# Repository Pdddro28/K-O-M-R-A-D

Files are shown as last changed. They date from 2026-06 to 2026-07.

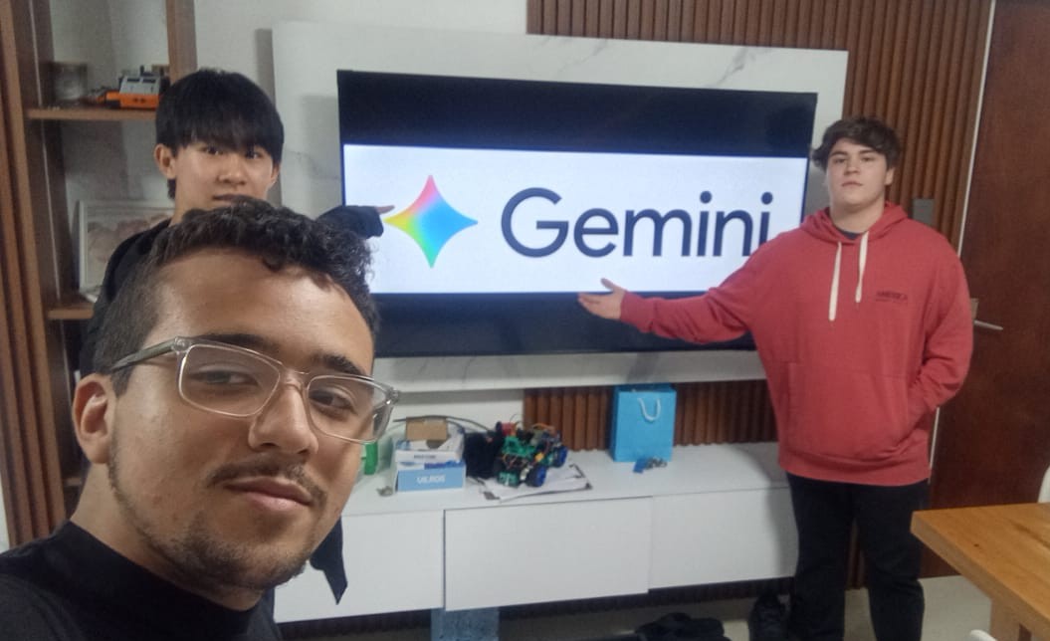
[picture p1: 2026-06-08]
t-photos/Funny_pic.jpg

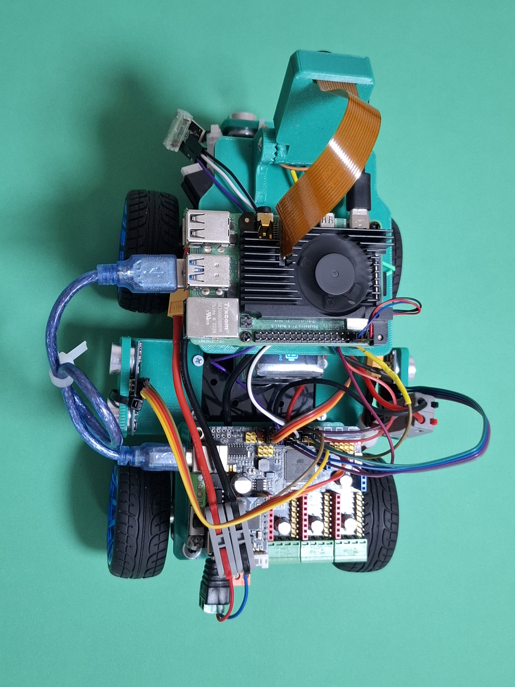
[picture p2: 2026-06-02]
v-photos/Upper-Pov.jpg

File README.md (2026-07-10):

**If you want to see this repository in English, [click here](https://github.com/Pdddro28/K-O-M-R-A-D/blob/main/README_EN.md)**

``` Para mejor visualización, se recomienda ver el repositorio en la computadora ```

# WRO 2026 Future Engineers – LNM

<div align="center">
	
<img width="840" height="407" alt="WhatsApp Image 2026-06-19 at 11 51 57 PM" src="https://github.com/user-attachments/assets/cee364df-eeba-4338-8f2a-14949adb755b" />

</div>

Bienvenidos al repositorio de GitHub del **Equipo LNM**, anteriormente conocido como Ars Machina, que compite en la categoría **World Robot Olympiad™ (WRO®) Future Engineers 2026**. Nuestro equipo está formado por David Wang y Pedro Catamo que han diseñado un vehículo autónomo compacto e innovador para hacer frente a los retos dinámicos de la competición WRO 2026.

## **Índice**

**1. [Estructura de carpetas](#estructura-de-carpetas)**

**2. [El equipo](#el-equipo)**

**3. [Nuestro robot](#nuestro-robot)**

**4. [Sistemas electrónicos](#sistemas-electronicos)**

**5. [Sistemas mecánicos](#sistemas-mecanicos)**

**5. [Arquitectura de software](#arquitectura-de-software)**

---

## **Estructura de carpetas** 

Esta es la estructura de carpetas de nuestro repositorio:

| Carpeta | Contenido técnico | Documentación detallada |
|---|---|---|
| **models** | **Diseños 3D**<br>• Piezas del carro| [Explora los modelos 3D](models/README.md) |
| **schemes** | **Sistemas eléctricos**<br>• Diagramas de cableado<br>• Gestión de la alimentación<br>• Esquemas de componentes| [Explora la documentación de esquemas y cableado](schemes/README.md) |
| **src** | **Algoritmos de software**<br>• Lógica de navegación<br>• Fusión de sensores<br>• Sistemas de control | [Explora la documentación de software y algoritmos](src/README.md) |
| **t-photos** | **Documentación del equipo**<br>• Perfiles de los miembros | [Explora la documentación de fotos del equipo](t-photos/README.md) |
| **v-photos** | **Documentación del vehículo**<br>• Vistas desde múltiples ángulos | [Explora la documentación de fotos del vehículo](v-photos/README.md) |
| **video** | **Validación del rendimiento**<br>• Demostraciones del desafío<br>• Pruebas de ingeniería | [Explora la documentación de los vídeos de rendimiento](video/README.md) |

---

## **El Equipo** 

<div align="center">
	
<img width="1280" height="720" alt="Team_pic (1)" src="https://github.com/user-attachments/assets/156c3c29-799e-44e6-a7f0-629da61873b8" />

</div>

### **Miembros:**

- **David Wang**
   
	Nacido en: 01/04/2011 (15 años)

	Estudio: 3º año en la U.E.C. Eduardo Blanco

  	Gmail: davidwangwu104@gmail.com
  	  
- **Pedro Catamo**
   
 	Nacido en: 28/01/2009 (17 años)
   
  	Estudio: 5º año en la U.E.C. Eduardo Blanco
   
 	 Gmail: pedrocatamo.2009@gmail.com

- ### **Coach:**

- **Jesús Alcalá**
   
  Nacido en: 18/11/2005 (21 Años)
   
  Estudio: Ingenieria en computación & Ingenieria informática
   
  Gmail: Jdam50002@gmail.com

---

### Diseños anteriores:
  
<div align="center">
	
| Foto | Nombre | Descripción |
|---|---|---|
| <img width="920" height="920" alt="Captura de pantalla 2026-06-17 185504" src="https://github.com/user-attachments/assets/36166165-a542-42d6-a771-41a60693a399" /> | **Cyber Cooper** | En 2023 teníamos pensado diseñar el coche desde cero, modelando e imprimiendo nuestras propias piezas en 3D, incluidos el chasis y el sistema de dirección. Aunque al principio parecía una buena idea, a medida que avanzábamos empezamos a encontrarnos con un problema tras otro, y nos dimos cuenta de que nuestro diseño actual nos acarrearía más dificultades. Al final, hicimos todo lo que pudimos dentro de las limitaciones de tiempo que teníamos. |
| <img width="920" height="920" alt="front2" src="https://github.com/user-attachments/assets/ce130237-cc0b-4aa9-a620-0aea287408c2" /> | **Cooper** | En 2024 desarrollamos un chasis con piezas 3D estructurado en dos niveles. El nivel inferior albergaba los sensores y la electrónica de bajo nivel, mientras que el superior sostenía las baterías y la Raspberry Pi 3 para optimizar el espacio. Aunque logramos un gran avance estético y funcional, sufrimos lecciones duras en pista: el peso excesivo provocó la flexión de los acoples en la transmisión trasera, lo cual, a su vez, generó problemas severos de fricción mecánica entre las piezas impresas en 3D. |
| <img width="920" height="920" alt="front" src="https://github.com/user-attachments/assets/804b3d7f-3500-4351-a917-ccf781029804" /> | **Halbi** | En 2025 teniendo en cuenta los recursos de los que disponíamos en ese momento, nuestra idea principal era rediseñar el Cybercooper, modificando la base y la estrategia existentes y utilizando mejores componentes electrónicos; empezamos a imprimir las nuevas piezas con material blanco y a pensar en mejores formas de montar el sistema de dirección del coche. Al final, decidimos utilizar una base prefabricada para el chasis; la razón principal fue ahorrar tiempo (y dolores de cabeza) con el diseño mecánico, lo que nos permitía dedicar más tiempo a la electrónica y la programación. |
| <img width="920" height="920" alt="WhatsApp Image 2026-06-18 at 7 39 40 PM" src="https://github.com/user-attachments/assets/ca9f62ff-7b8b-452a-97de-95ebf12dc0ef" /> | **The Fridge** | En 2025 a diferencia de los modelos anteriores que pertenecían a nuestro coach, "The Fridge" fue un diseño construido enteramente por nosotros. Aquí dimos el salto a la geometría Ackermann e imprimimos la gran mayoría de las piezas en 3D. A nivel motriz, usamos un motor DC con un engranaje acoplado para traccionar ambas ruedas. Físicamente le instalamos 3 sensores ultrasónicos, una Raspberry Pi 4 y un giroscopio MPU6050, pero por falta de tiempo y severos problemas de configuración, la Raspberry y el IMU quedaron como peso muerto y terminamos controlando todo únicamente desde la MegaPi. Sufrimos muchísimo: las piezas de la dirección impresas en 3D se rompían constantemente por el estrés, y programar la navegación autónoma en Arduino dependiendo de puros rebotes ultrasónicos fue casi imposible. |

</div>

---

# 1- Mobilidad y diseño

 - ### Halbi The Green: 

    - ### Fotos del vehiculo:

	<div align="center">

	| | **Diferentes ángulos del carro** | |
	|---|---|---|
	| **Superior** | **Derecha** | **Izquierda** |
	| <img width="560" height="580" alt="Upper-Pov" src="https://github.com/user-attachments/assets/74863cc8-5128-49cf-845e-0f087c50bcf1" /> | <img width="560" height="580" alt="RightSide-Pov" src="https://github.com/user-attachments/assets/8b9c2020-cc18-441f-9152-c86d9a233b10" /> | <img width="560" height="580" alt="LeftSide-Pov" src="https://github.com/user-attachments/assets/cdbabe27-6e45-4dab-98e6-e63b24ed7371" /> |
	|**Frontal** | **Trasero** | **Inferior** |
	| <img width="560" height="580" alt="Front-Pov" src="https://github.com/user-attachments/assets/d9b65dd5-ca97-4087-ba20-77f7cbeb4bf6" /> | <img width="560" height="580" alt="Back-Pov" src="https://github.com/user-attachments/assets/dd1737be-1173-4cae-9229-25821f05dc22" /> | <img width="560" height="580" alt="Lower_Pov" src="https://github.com/user-attachments/assets/4c77c94d-d121-4708-b3ed-74bc2d390fe6" /> |
	
    </div>

	- ### Especificaciones mecánicas principales: 

		- **Dimensiones totales: 24.4 cm (largo) × 15.4 cm (ancho) × 15.9 cm (alto).**
		- **Peso del carro: aproximadamente 1.2kg.**
		- **Sistema de tracción: Tracción Trasera Mecánica Bifásica.**
		- **Sistema de dirección: Geometría Ackermann.**
	
	- ### Mecanismo de Dirección Ackermann

		El vehículo utiliza una geometría precisa basada en el **Principio de Dirección Ackermann** para conquistar curvas cerradas con cero deslizamiento lateral y un desgaste mínimo de los neumáticos.

		* **La Física Detrás del Principio:** Cuando un vehículo entra en una curva, la rueda delantera interior sigue un radio concéntrico más cerrado y pequeño que la rueda exterior. Si ambas ruedas giraran exactamente al mismo ángulo, los neumáticos lucharían entre sí, provocando que el neumático exterior se arrastre, pierda agarre mecánico e introduzca vibraciones estructurales severas que arruinarían el seguimiento visual de los carriles. Para resolver esto, la geometría mecánica obliga a la rueda interior a pivotar a un ángulo más profundo que la rueda exterior, asegurando que las cuatro ruedas roten alrededor de un único centro instantáneo de curvatura (ICC) común.

		* **La Ejecución Mecánica:** Un servo digital **MG996R** de alto par ($11 \text{ kg}\cdot\text{cm}$ de par) se ancla al mamparo delantero mediante un soporte de aluminio en forma de L mecanizado a medida para eliminar la deflexión estructural. El brazo del servo acciona una cremallera de dirección de doble enlace conectada a tirantes asimétricos y manguetas de dirección. Los brazos de dirección están angulados hacia el interior, apuntando al centro del eje trasero, completando el clásico "Trapezoide de Ackermann". Este diseño mecánico exacto convierte el desplazamiento lineal del servo en ángulos de rueda no lineales de forma automática.

		* **El Control Digital y Calibración:** El MG996R es controlado por un tren de pulsos PWM por hardware continuo y libre de fluctuaciones (*jitter*) a $50\text{Hz}$ directamente desde el microcontrolador MegaPi. La dirección está rígidamente mapeada y calibrada a una banda muerta de software donde los $80^\circ$ representan el centro geométrico absoluto. Los puntos finales mecánicos están limitados por software entre $40^\circ$ (Máximo Izquierda) y $105^\circ$ (Máximo Derecha) para evitar que los eslabones de la dirección alcancen un bloqueo mecánico o fuercen los límites de pérdida del motor.

	- ### ¿Qué es la Geometría Ackermann? 

		Entendiendo la Matemática y Cinemática Ackermann, en robótica móvil tradicional (como los robots de la categoría *RoboMission*), se utiliza la tracción diferencial porque es matemáticamente simple: varías la velocidad de dos motores y el robot gira sobre su propio eje. Sin embargo, a altas velocidades, la tracción diferencial es inestable e impredecible.

		**La Geometría Ackermann** resuelve esto mediante un principio puramente mecánico. Para que un vehículo gire sin deslizarse lateralmente, las líneas extendidas desde los ejes de todas las ruedas deben cruzarse en un único punto en el espacio: el **Centro Instantáneo de Rotación (CIR)** o ICC.

		La ecuación matemática fundamental que gobierna esta cinemática es:
		<div align="center">
	
		$$\cot(\theta_{\text{out}}) - \cot(\theta_{\text{in}}) = \frac{w}{L}$$
		
		</div>
		
		Donde:
		
		* $\theta_{\text{in}}$ es el ángulo de giro de la rueda interna.*
		* $\theta_{\text{out}}$ es el ángulo de giro de la rueda externa.*
		* $w$ es el ancho de la vía (*track width* o distancia entre las ruedas frontales).*
		* $L$ es la batalla del carro (*wheelbase* o distancia entre el eje delantero y trasero).*

		Dado que la cotangente crece más rápido a ángulos pequeños, esta relación obliga mecánicamente a que $\theta_{\text{in}} > \theta_{\text{out}}$ de forma automática en cualquier curva, abriendo el ángulo de la rueda exterior para que dibuje un círculo más grande.

		<div align="center">
  
		<img width="567" height="600" alt="17523247_203569336801744_2788986523412924047_n" src="https://github.com/user-attachments/assets/c36a271c-b45c-492a-805e-b107851429cd" />
		
		</div>

	- ### Propulsión Electrónica 2WD con Transmisión Mecánica Bifásica 

		La fuerza motriz de la plataforma se genera mediante un sistema de tracción trasera (2WD) de alto rendimiento, el cual rompe con los esquemas tradicionales de acoplamiento directo al integrar una transmisión mecánica desmultiplicada de dos velocidades por engranajes cilíndricos rectos.

		* **Arquitectura del Sistema de Transmisión:** A diferencia de las configuraciones comunes que acoplan la rueda directamente a la caja reductora del motor, este diseño monta el motor RS380 en una disposición paralela superior sobre un bloque de soporte rígido. La potencia se transfiere desde el eje primario del motor hacia un eje secundario de tracción inferior mediante un tren de engranajes expuesto con dentado recto. Este sistema de dos velocidades mecánicas intercambiables permite configurar el robot según las exigencias de la pista:
  		1. **Relación de Fuerza/Torque (Primera Velocidad):** Optimiza el desmultiplique para obtener la máxima aceleración y un control milimétrico en curvas cerradas u obstáculos, ideal para tramos revirados. 
  		2. **Relación de Velocidad Final (Segunda Velocidad):** Reduce la pérdida de revoluciones para aprovechar la inercia lineal en rectas largas, garantizando una alta velocidad de crucero sin saturar el consumo eléctrico.

		<div align="center">
  
		<img width="515" height="218" alt="Sistema de transmision de 2 velocidades K-O-M-R-A-D" src="https://github.com/user-attachments/assets/da8175e6-313d-42d6-bd3b-b1318082536f" />
		
		</div>

		* **Especificaciones Técnicas de los Motores (RS380):** El bloque motriz confía en motores de CC con escobillas imantadas, seleccionados específicamente por su curva de respuesta dinámica y tolerancia a picos transitorios de carga.

	    * **Voltaje Nominal:** $12\text{V}$ (Operando a un voltaje nominal de celda de $11.1\text{V}$ mediante una batería LiPo 3S para asegurar la estabilidad térmica).
   
 		* **Corriente de Vacío (No-load):** $0.3\text{A}$ | **Corriente de Arranque/Pérdida (Stall):** $3\text{A}$ de protección en el driver.
   
 		* **Velocidad de Rotación de Fábrica:** $15000\text{ RPM}$ en el núcleo del motor, reducida internamente y ajustada finalmente por el engranaje externo para entregar una velocidad final estimada de transferencia de aprox. $450\text{ RPM}$ en el eje de la rueda.

		* **Análisis Cinemático y Cálculo de la Velocidad Teórica Absoluta:**
		Para determinar el rendimiento del chasis en pista y calibrar las ventanas de tiempo por vuelta (como el parámetro de control `lap_time = 4.3`), se realiza el cálculo cinemático basado en el diámetro de las ruedas motrices de $6.5\text{ cm}$ ($0.065\text{ m}$). Evaluamos la circunferencia de rodadura ($C$) y la velocidad lineal máxima teórica ($V$):

	<div align="center">
	
	$$C = \pi \times 0.065\text{ m} \approx 0.2041\text{ m}$$

	</div>

	Transformando las revoluciones por minuto del eje secundario de la transmisión a revoluciones por segundo y multiplicando por el desarrollo de la circunferencia, obtenemos la velocidad de avance del chasis:

	<div align="center">
	
	$$V = \frac{450\text{ RPM}}{60} \times 0.2041\text{ m} \approx 1.53\text{ m/s}$$
		
	</div>

	Este valor de $1.53\text{ m/s}$ representa la velocidad límite ideal de la plataforma. En condiciones reales de competencia, este vector se modula por software mediante los comandos de velocidad (`speed = 90` u `80`) para absorber la fricción estática del suelo, la resistencia al avance de los rodamientos y las demandas instantáneas de corriente solicitadas por la MegaPi al gestionar el cambio de inercias.

	- ### 3D Printed Parts:

   		- #### **Piezas:**

		<div align="center">
			
		| Component & Preview | Design & Geometry | Engineering Purpose |
		|---|---|---|
		| **Battery Case** <br><br><img width="400" height="400" alt="BatteryCase" src="https://github.com/user-attachments/assets/a5362844-dd0e-4073-bef8-bb034bae3ad9" /> | Diseñado como una jaula de torre vertical estructurada con cuatro pilares reforzados en cada lado, integrada directamente sobre una base de montaje sólida con ojales para tornillos en las esquinas. Las paredes laterales cuentan con grandes recortes circulares para minimizar el peso del material mientras permiten un flujo de aire pasivo máximo para evitar el estrés térmico en las celdas LiPo durante altas tasas de descarga. El pilar superior incluye ojales de retención ranurados para una sujeción segura de las correas. | Centraliza la masa combinada de las celdas de la batería verticalmente a lo largo del eje geométrico central del chasis. Este diseño de jaula abierta garantiza un acceso rápido para el reemplazo de la batería entre carreras, al tiempo que proporciona una contención estructural rígida contra las fuerzas de inercia laterales durante giros a alta velocidad. |
		| **Camera Case** <br><br><img width="400" height="400" alt="CameraCase" src="https://github.com/user-attachments/assets/7adbc42b-15eb-4677-a0a4-8d9b3c98bab3" /> | Una carcasa protectora rectangular y compacta, diseñada específicamente para encapsular el sensor IMX219 (Arducam). La sección inferior integra una robusta bisagra de pivote cilíndrico que cuenta con dientes de bloqueo externos (perfil de engranaje recto) diseñada para engranar perfectamente con una base de montaje correspondiente para el bloqueo mecánico del ángulo. | Protege el delicado PCB de la cámara de los escombros externos o de los impactos directos en la pista. La bisagra engranada entrelazada permite ajustar y bloquear mecánicamente el ángulo de inclinación de la cámara a un ángulo preciso de 15 grados hacia abajo, evitando cualquier cambio no deseado en el lente causado por las vibraciones de alta frecuencia del chasis durante la operación. |
		| **MegaPi Case** <br><br><img width="400" height="400" alt="MegaPiBase (1)" src="https://github.com/user-attachments/assets/8db95bf2-a29a-468c-ace8-e21bb1fae9f6" /> | Una bandeja robusta de perfil bajo equipada con cuatro soportes verticales integrados de alta resistencia posicionados en las esquinas para asegurar el PCB principal. La placa base cuenta con guías de distribución internas y cortes de holgura estructural para evitar los componentes en la parte inferior de la placa, manteniendo el perfil lo más cercano posible al chasis. | Funciona como una cuna mecánica rígida para la electrónica de potencia de bajo nivel. Al elevar el PCB mediante los soportes integrados de 3 mm, evita cortocircuitos eléctricos con el chasis al tiempo que amortigua las vibraciones. El perímetro completamente abierto garantiza el acceso inmediato a los terminales de tornillo del motor, los rieles de alimentación y los puertos de sensores para el mantenimiento en campo. |
		| **RaspberryPi Base** <br><br><img width="400" height="400" alt="RaspberryPiBase (1)" src="https://github.com/user-attachments/assets/2403b708-2e1d-4360-9504-aae68c0027d1" /> | Una plataforma modular plana de nivel medio que cuenta con cuatro soportes de esquina integrados para montar la Raspberry Pi 4 de forma segura. La sección frontal de la base integra un montaje de bisagra de doble oreja equipado con dientes de bloqueo internos que se acoplan directamente con la bisagra de la carcasa de la cámara (Camera Case). | Sirve como un puente estructural de doble propósito. Proporciona un montaje estable y elevado para la computadora de a bordo de alto nivel, asegurando una disipación óptima del calor a través de la convección natural para evitar el estrangulamiento térmico del CPU. Al mismo tiempo, su montaje engranado integrado bloquea firmemente el ensamblaje de la cámara en la parte delantera, eliminando la necesidad de componentes adicionales y ahorrando valioso espacio en el chasis.|
		| **Ultrasonic Case** <br><br><img width="400" height="400" alt="UltrasonicSensorCase" src="https://github.com/user-attachments/assets/f9696c40-13e6-46b5-9712-2d7849a80005" /> | Un soporte protector compacto de doble barril hecho a medida para encapsular firmemente los cilindros del transmisor y receptor del módulo del sensor ultrasónico. Cuenta con pestañas de montaje traseras integradas y bridas inferiores para un acoplamiento mecánico continuo a las vigas transversales delanteras de la estructura del chasis. | Proporciona una carcasa rígida y aislada de vibraciones que mantiene el sensor ultrasónico perfectamente perpendicular al plano horizontal de la pista. Esta alineación precisa elimina la distorsión de la señal acústica y la dispersión de las ondas, garantizando mediciones de distancia en tiempo real altamente precisas para la detección de obstáculos y mapas de frenado de emergencia. |

		</div>

		- #### **Impresora:** Se usó las impresoras Creality Hi y Creality K1.

   			- **Creality Hi:** Es una de las propuestas más recientes de Creality, diseñada con un fuerte enfoque en competir directamente en el mercado de impresión multicolor accesible.
        
        		- **Volumen de construcción (lo que puedes imprimir):** $260 \times 260 \times 300\text{ mm}$. Es un tamaño intermedio-alto, excelente para robótica porque te permite hacer chasis completos en una sola pieza sin tener que segmentarlos.
            
          		- **Dimensiones de la máquina:** $409 \times 392 \times 477\text{ mm}$ (Peso: $8.75\text{ kg}$).
  
        		Es una impresora cartesiana de alta velocidad equipada con motores step-servo en los ejes X/Y para evitar la pérdida de pasos. Su gran fuerte es la compatibilidad nativa con el sistema CFS (Creality Filament System), un módulo externo tipo "banco de filamentos" que te permite alternar de forma automatizada hasta 4 colores diferentes (o hasta 16 si encadenas 4 módulos). Su velocidad máxima es de $500\text{ m/s}$ con una aceleración de $12,000\text{ mm/s}^2$ y alcanza los $300^\circ\text{C}$ en la boquilla.
  
        		- **¿Qué tan buena es?**
  
           			* **Puntos Fuertes:** Estructura de aluminio fundido extremadamente rígida, calibración y nivelación 100% automática por sensor de deformación, y detección inteligente de enredos o fin de filamento. Si compras la versión Combo (con el CFS), es una máquina brutal para piezas que necesitan soportes solubles o combinar materiales rígidos y flexibles.
  
       				* **Puntos Débiles:** Al no ser cerrada de fábrica (diseño abierto), imprimir materiales técnicos propensos a contraerse como el ABS o ASA de forma consistente puede ser complicado sin construirle una cabina externa.
          
	   			- **¿Se recomienda usarla a futuro?**
  
   					Sí, totalmente. Al ser una plataforma moderna, cuenta con el soporte de software más actualizado (Creality Print 5.1 / OrcaSlicer) y está diseñada bajo el ecosistema de cambio de filamento automático, que es hacia donde se mueve toda la industria. Es una excelente inversión a largo plazo para un taller.

			- **Creality K1:** Lanzada originalmente como la respuesta directa de Creality a la serie P1 de Bambu Lab, es una máquina de nivel profesional diseñada para velocidad pura y materiales exigentes.

     			- **Volumen de construcción (lo que puedes imprimir):** $220 \times 220 \times 250\text{ mm}$. Es un espacio estándar (ligeramente más pequeña que la Creality Hi).
        
    			- **Dimensiones de la máquina:** $355 \times 355 \times 480\text{ mm}$ (Peso: $12.5\text{ kg}$).
  
        		Utiliza un sistema cinemático CoreXY donde el cabezal se mueve de forma ultraligera en los ejes X/Y usando correas cruzadas, mientras la cama solo baja en el eje Z. Al estar completamente cerrada con paneles de vidrio y acrílico, retiene el calor interno en la cámara de impresión. Alcanza una velocidad de $600\text{ mm/s}$ y una aceleración masiva de $20,000\text{ mm/s}^2$ gracias a su firmware basado en Klipper (Creality OS).
  
   				- **¿Qué tan buena es?**
  
   					* **Puntos Fuertes:** Es una bestia para materiales técnicos. Su cámara cerrada es perfecta para imprimir PETG, ABS, ASA y Nylon sin sufrir warping (despegue de bordes). Su aceleración es casi el doble que la de la Creality Hi, reduciendo los tiempos de impresión de piezas mecánicas complejas drásticamente.
  
       				* **Puntos Débiles:** Las primeras unidades que salieron al mercado (lotes de 2023) sufrieron de problemas en el extrusor (versión V1) y en el hotend. Creality corrigió esto en las versiones posteriores (extrusor con palanca brillante y boquilla tipo Unicorn), por lo que si adquieres una hoy, te aseguras de tener la versión corregida y madura.
          
	   			- **¿Se recomienda usarla a futuro?**
  
   					Sí, pero bajo ciertas condiciones. Sigue siendo una máquina excepcionalmente rápida y robusta para piezas de ingeniería. Sin embargo, debes tener en cuenta que la K1 original no es compatible con sistemas de impresión multicolor multihilo modernos de manera nativa (esa característica se reservó para la serie K2 con el nuevo CFS).

		- #### **PETG vs PLA:**

		<div align="center">

		|  | PETG | PLA |
		|---|---|---|
		| **Durabilidad y Resistencia** | Alta durabilidad y tenacidad superior: Al estar modificado con glicol, el PETG impide la cristalización del polímero, resultando en un material altamente tenaz. Bajo esfuerzos mecánicos por impacto, sus cadenas moleculares tienen la flexibilidad necesaria para deformarse elásticamente y absorber la energía cinética del choque. Esto evita la propagación de grietas, haciéndolo ideal para piezas expuestas a colisiones continuas. | Baja durabilidad ante cargas dinámicas: El PLA posee una estructura molecular rígida y cristalina que le otorga una alta dureza superficial, pero carece de la capacidad de disipar energía de forma elástica. Ante colisiones directas o impactos bruscos contra los bordes de la pista, el material estresa sus uniones de capa interlace y tiende a la fractura frágil, quebrándose de manera repentina y catastrófica en lugar de flexionarse. |
		| **Resistencia y Estabilidad Térmica** | Excelente inmunidad térmica: Mantiene su integridad estructural y rigidez mecánica en entornos de trabajo de hasta 75°C a 80°C sin experimentar ablandamiento ni distorsión geométrica. Esta propiedad permite montarlo con total seguridad como soporte directo del tren motriz o de placas electrónicas, resistiendo el calor generado por la fricción mecánica y los picos de corriente sin ceder. | Vulnerable al estrés térmico: Su temperatura de transición vítrea (punto de ablandamiento) es críticamente baja, situándose entre los 50°C y 55°C. Si se utiliza en componentes en contacto directo con motores DC bajo carga pesada o reguladores de voltaje que disipan calor por conducción, el PLA pierde su rigidez rápidamente, sufriendo deformaciones geométricas permanentes que descalibran el chasis. |
		| **Rigidez Estructural y Flexión** | Módulo elástico moderado (Flexibilidad elástica): Posee una naturaleza semirrígida que le permite soportar vibraciones mecánicas, torsiones y cargas dinámicas continuas sin sufrir fatiga de material. Si bien cede ligeramente ante fuerzas extremas antes de romperse, esta flexibilidad estructural absorbe las oscilaciones del terreno, protegiendo los componentes internos. | Módulo elástico muy elevado (Rigidez absoluta): Presenta una resistencia a la flexión superior, lo que significa que no se dobla ni se deforma bajo cargas estáticas moderadas. Esta ausencia de flexibilidad elástica es una ventaja técnica para piezas estáticas del robot que requieren mantener una posición fija e invariable, neutralizando cualquier flexión parasitaria o pandeo. |
		| **Resistencia Química y Ambiental** |  Alta inercia química e hidrofobicidad: Es químicamente inerte y exhibe una resistencia sobresaliente ante aceites, grasas, lubricantes mecánicos y alcoholes de limpieza. Al ser completamente hidrofóbico, no se debilita por la humedad ambiental tras su impresión y su alta estabilidad frente a la radiación UV garantiza que las piezas mantengan sus propiedades mecánicas intactas. | Sensible a la degradación a largo plazo: Al ser un biopolímero derivado de fuentes orgánicas, es propenso a la degradación acelerada bajo la exposición continua a rayos UV o cambios de humedad drásticos. Además, su resistencia química frente a agentes externos como alcoholes, aceites o lubricantes de hardware es limitada, lo que puede debilitar las paredes de la pieza con el tiempo. |
		| **Precisión Dimensional y Encajes** | Tolerancias moderadas y propenso a hilos: Al requerir temperaturas de extrusión más altas, el material experimenta una mayor contracción térmica al enfriarse, lo que exige calibrar el flujo para evitar variaciones dimensionales en encajes milimétricos. Además, su alta viscosidad tiende a generar stringing (hilos finos) que requieren postprocesado en zonas de movimiento mecánico fino. | Tolerancias geométricas perfectas: Debido a su bajísima contracción térmica al enfriarse, el PLA destaca por una estabilidad dimensional milimétrica. Permite imprimir roscas, encajes de rodamientos y uniones mecánicas finas con errores de tolerancia prácticamente nulos, asegurando que las piezas encajen de manera exacta y sin holguras desde el primer prototipo. |
	
		</div>

# 2. Componentes 

- ### Precios:

<div align="center">

| Cantidad | Productos | Precio | Total |
|---|---|---|---|
| 1 | [Raspberry Pi 4 B](https://www.amazon.com/Raspberry-Model-2019-Quad-Bluetooth/dp/B07TC2BK1X) | $123.99 | $123.99 |
| 1 | [Yfrobot steering chassis](https://yfrobot.com/products/steering-gear-robot) | $118.50 | $118.50 |
| 2 | [Zeee 3S Lipo Battery 2200mAh 11.1V 50C](https://www.amazon.nl/Zeee-Vrachtwagen-Vliegtuig-Quadcopter-Helikopter/dp/B0C2CHMCC3) | $50.65 | $101.3 |
| 1 | [Arducam 8MP IMX219 175°](https://www.amazon.com/Arducam-IMX219-Degree-Raspberry-Compatible/dp/B09VSVB4DT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) | $26.99 | $26.99 |
| 4 | [Lever wire connectors](https://www.amazon.com/Conductor-Compact-Connectors-Electrical-Terminals/dp/B0D9Y5XFQC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) | $9.99 | $39.96 |
| 1 | [Buck Converter 3A 15W Type-C](https://www.amazon.com/-/es/Convertidor-Impermeable-Adaptador-corriente-compatible/dp/B0D2MTJQK8) | $8.79 | $8.79 |
| 1 | [MAKEBLOCK MegaPi (from mbot mega)](https://www.robotshop.com/products/makeblock-mbot-mega-robot-car-rechargeable-li-po-battery-kit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) | $148.97 | $148.97 | 
| 3 | [Ultrasonic Sensor HC-SR04](https://www.amazon.com/-/es/Ferwooh-ultras%C3%B3nico-HC-SR04-medici%C3%B3n-distancia/dp/B0D1MDP9V3) | $6.99 | $20.97 |
| Total | | | **$589.47** |

</div>

- ### Descripción:

<div align="center">

| Foto | Descripción |
|---|---|
| **Yfrobot kit** <div  align="center"> <div  style="width:290 px"> ![halbi](https://funduinoshop.com/media/image/84/6f/82/YFROBOT-chassis-kit-mit-lenkachse-technische-zeichnung_600x600@2x.png) </div> </div>  | El chasis modular YFROBOT 4WD combina tracción en las cuatro ruedas con un sistema de dirección tipo automóvil para ofrecer mayor estabilidad y un control preciso. Diseñado con soportes específicos para controladores como Arduino o Raspberry Pi, simplifica el ensamblaje mecánico y permite añadir sensores o accesorios fácilmente. Al reducir la complejidad del diseño desde cero, resulta una plataforma ideal en educación y competiciones para que los equipos se concentren directamente en la programación, la navegación autónoma y los sistemas de control. |
| **Raspberry PI 4 B** <div align="center"> <img width="293" height="172" alt="images" src="https://github.com/user-attachments/assets/5c007a1e-273e-4ce2-89a7-fa99dd9b069b" /> </div> | La Raspberry Pi 4 Modelo B es un potente ordenador de placa única (SBC) del tamaño de una tarjeta de crédito desarrollado por la Fundación Raspberry Pi. Se utiliza ampliamente en robótica, proyectos de IoT y 	sistemas embebidos debido a su versatilidad, rendimiento y precio asequible. |
| **Makeblock MegaPi** <div  align="center"> ![nano](https://ardubotics.eu/10754/makeblock-mega-pi-born-to-control.jpg) </div> | Se seleccionó la placa **Makeblock MegaPi** (**ATmega2560**) como microcontrolador central por su capacidad para gestionar múltiples motores y sensores simultáneamente, superando a opciones como Arduino Uno o Nano gracias a sus interfaces plug-and-play. Aunque está diseñada para acoplarse directamente sobre una Raspberry Pi, se optó por conectarla únicamente vía **USB** para la transferencia de datos. Esta alternativa optimiza el espacio del chasis, aprovecha que la MegaPi cuenta con alimentación propia y evita exponer la placa principal a riesgos durante el proceso de soldadura. |
| **Zeee 3S Lipo Battery 2200mAh 11.1V 50C** <div  align="center"> <div  style="width:290 px"> ![LX2-BUSB](https://m.media-amazon.com/images/I/71-SIfPk3XL._AC_UF1000,1000_QL80_.jpg) </div> | El robot utiliza una batería LiPo Zeee 3S (2200mAh, 11.1V, 50C) como fuente de energía única, elegida por su alta tasa de descarga y un diseño compacto que optimiza el espacio en el chasis frente a opciones más voluminosas. Esta configuración simplifica el sistema al alimentar tanto la lógica como los motores, aunque exige el uso de reguladores de voltaje externos (como convertidores CC-CC) para proteger componentes sensibles como la Raspberry Pi. A pesar de requerir un manejo cuidadoso con cargadores específicos para evitar riesgos y prolongar su vida útil, ofrece un balance excelente entre potencia, tamaño y rendimiento para aplicaciones robóticas. |
| **Steering servo mg996r** <div  align="center"> ![L298N](https://cdn-global-hk.hobbyking.com/media/catalog/product/cache/10/image/9df78eab33525d08d6e5fb8d27136e95/6/2/6221_1_high_7_.jpg) </div> | Incluido en el kit de YFROBOT para controlar el eje de dirección, el MG996R es un servomotor digital de alto torque que opera mediante señales PWM en un rango de 0° a 180°. Su piñonería metálica le otorga una mayor durabilidad y fuerza frente a los servos de plástico, permitiéndole soportar cargas mecánicas exigentes. Con un rango de operación de 4.8V a 6V, ofrece un torque de entre 9.4 y 11 kg·cm y velocidades de hasta 0.15 segundos por cada 60°, utilizando una interfaz estándar de tres pines totalmente compatible con microcontroladores como Arduino y Raspberry Pi. |
| **RS380 motor** <div  align="center"> ![motor](https://novatronicec.com/wp-content/uploads/2020/10/Motor-con-caja-reductora-25GA370_2.jpg) </div> | El conjunto de motor RS-380 con caja reductora es un sistema de corriente continua compacto y versátil, ideal para robótica pequeña y automatización ligera. Por sí solo, el RS-380 es un motor con escobillas de tamaño reducido que gira a altas revoluciones (entre 10 000 y más de 20 000 RPM según el voltaje) pero genera muy poco torque. La incorporación de la caja reductora soluciona esta limitación al disminuir la velocidad de giro mediante una serie de engranajes, lo que incrementa significativamente el torque de salida y permite al sistema mover cargas mecánicas más pesadas de manera práctica. |
| **ArduCam IMX219 8MP** <div  align="center"> ![Encorder](https://cdn.arducam.com/wp-content/uploads/2022/04/Arducam_IMX219_MIPI_Pi_B0392-8.jpg) </div> | La ArduCam IMX219 de 8MP es un módulo de cámara compacto basado en el sensor Sony IMX219, el mismo estándar de la Raspberry Pi Camera v2, que equilibra resolución y rendimiento para proyectos de visión artificial y robótica. Se conecta mediante la interfaz CSI (Camera Serial Interface), lo que garantiza una transferencia de datos a alta velocidad y con baja latencia hacia computadoras como Raspberry Pi o Jetson Nano. Este diseño la convierte en una solución eficiente y de fácil integración para sistemas embebidos que requieren procesamiento de imagen en tiempo real. |
| **Buck Converter 3A 15W Type-C** <div  align="center"> ![camera](https://m.media-amazon.com/images/I/61pOfxNxUnL._AC_UF1000,1000_QL80_.jpg) </div> | El módulo **convertidor buck tipo C de 3A y 15W** es un regulador reductor de CC-CC que transforma voltajes de entrada elevados en una salida baja y estable con una eficiencia del 85 al 95%. En este proyecto, se utilizó para conectar la batería **LiPo Zeee 3S** (de hasta 12.6V) a la **Raspberry Pi 4B**, la cual exige un suministro constante de **5V y hasta 3A**. Debido a que el voltaje directo de la batería dañaría la placa, el convertidor reduce y regula la tensión de manera segura, protegiendo los componentes contra sobrevoltajes, minimizando las pérdidas de energía por calor y garantizando un rendimiento estable del sistema a medida que la batería se descarga. |
| **Ultrasonic Sensor HC-SR04** <div  align="center"> <img width="466" height="466" alt="61CXJgLZwUL _SX466_" src="https://github.com/user-attachments/assets/1345b129-76f7-4f39-8ec2-b839398ea61b" /> </div> | El sensor ultrasónico HC-SR04 es un dispositivo compacto de medición de distancia que opera bajo el principio del eco de sonar, ideal para la evasión de obstáculos en robótica. Está equipado con dos transductores que emiten una ráfaga de ondas de alta frecuencia ($40\text{ kHz}$) y reciben su rebote tras chocar con un objeto. Al calcular con precisión el tiempo que tarda la señal en ir y venir, el módulo determina la distancia lineal en un rango efectivo de 2 a 400 centímetros con una precisión de 3 milímetros, proporcionando datos en tiempo real cruciales para la navegación del vehículo.|

</div>

- ### **Disposición de Componentes y Justificación:**

	El diseño de nuestro vehículo autónomo se fundamenta en una arquitectura modular de tres niveles verticales, optimizada para la gestión eficiente del centro de gravedad, el balance de masas y la mitigación de interferencias electromagnéticas y mecánicas. Esta configuración jerárquica por "pisos" permite aislar los elementos mecánicos de potencia frente a los módulos lógicos de procesamiento y visión artificial.

	- **Arquitectura del Chasis por Niveles:**

	- **1st Level (Planta Baja):**
	Constituye la base estructural y el tren de rodaje del vehículo. En este nivel se ubica el Motor de Tracción RS380, el mecanismo de dirección asistido por el servomotor, y los tres sensores ultrasónicos HC-SR04 (Front-US y los sensores laterales Left-US / Right-US).

		- *Justificación Técnica:* Colocar los actuadores más pesados y el sistema de tracción en la planta baja garantiza un centro de gravedad lo más cercano posible al suelo, proporcionando estabilidad cinemática y tracción máxima en las ruedas traseras durante aceleraciones bruscas.
    
	- **2nd Level (Planta Intermedia):**
Situado inmediatamente arriba de la transmisión, este nivel alberga el núcleo de control de bajo nivel y la distribución eléctrica principal. Aquí se encuentran fijadas la placa de expansión Makeblock MegaPi, el Buck Converter (3A 15W) y la jaula vertical contenedora de las Baterías LiPo.

		- *Justificación Técnica:* La MegaPi actúa como puente físico intermedio para acortar las trayectorias del cableado hacia los motores del primer nivel. Al centralizar las baterías pesadas en este piso medio y alineadas horizontalmente con el centro de masa, se reducen los momentos de inercia polares, evitando subvirajes o sobrevirajes en las curvas cerradas de la pista. El Buck Converter se sitúa estratégicamente al lado de la MegaPi para reducir y estabilizar el voltaje proveniente de las celdas antes de enviarlo al nivel superior.
    
	- **3rd Level (Planta Superior):** Corresponde a la cúspide de la estructura, dedicada de forma exclusiva al procesamiento de alto nivel y la percepción geométrica. Contiene la computadora a bordo Raspberry Pi 4 B (equipada con su disipador térmico y ventilador activo) y el conjunto elevado de la cámara de visión artificial Arducam IMX219.

		- *Justificación Técnica:* Elevar la Raspberry Pi 4 la aísla por completo de las vibraciones mecánicas directas del motor de tracción y de los bucles de corriente del chasis inferior. Asimismo, la posición superior favorece la convección térmica del ventilador para evitar el estrangulamiento térmico (thermal throttling) del CPU durante la ejecución de los algoritmos de detección.

	**Sistema de Percepción y Orientación Espacial:**
	Esta distribución en tres dimensiones complementa la estrategia de nuestro sistema de percepción mixto (Visión + Acústica), asegurando zonas de cobertura óptimas sin interferencias mutuas:

	Esta distribución en tres dimensiones complementa la estrategia de nuestro sistema de percepción mixto, asegurando zonas de cobertura óptimas sin interferencias mutuas:

	- **Distribución de Visión Artificial (3rd Level):**
	La cámara Arducam IMX219 se posiciona en el punto más alto y adelantado del tercer nivel, sostenida por un brazo articulado impreso en 3D con un ángulo de inclinación fijo hacia abajo de 15 grados. Esta elevación es crítica para expandir la línea de visión del lente de 175°, permitiendo al algoritmo abarcar una Región de Interés (ROI) más amplia de la pista para identificar los códigos de color (semáforos) y líneas guía sin que la propia estructura del carro obstruya el encuadre.

	- **Distribución Ultrasónica Frontal (1st Level):**
	El sensor ultrasónico delantero (Front-US) se monta directamente sobre la placa base del chasis en una posición baja y avanzada, justo por debajo de la línea de proyección de la cámara. Esta sincronización geométrica permite que, mientras la cámara procesa las decisiones lógicas en el nivel superior, el ultrasonido actúe en el nivel inferior como un bypass de seguridad de hardware en tiempo real, detectando la presencia física de obstáculos de forma matemática y directa para activar frenados de emergencia.

	- **Distribución Láser de Precisión ToF (1st Level, Flanqueo Frontal):**
Ubicados a los flancos del sensor ultrasónico central, los sensores láser VL53L0X-V2 se han instalado con un ligero offset de profundidad. Esta configuración permite que el HC-SR04 actúe como parachoques protector, mientras los haces infrarrojos de los ToF actúan como perfiladores direccionales de alta resolución. Esta configuración garantiza que los obstáculos cilíndricos estrechos sean detectados con precisión milimétrica, blindando los puntos ciegos laterales del ultrasonido a corta distancia.

	- **Distribución Ultrasónica Lateral (1st Level):**
	Los dos sensores ultrasónicos de flanco (Left-US y Right-US) están anclados rígidamente a los costados izquierdo y derecho del primer nivel, posicionados de forma longitudinal entre ambos ejes de ruedas y alineados verticalmente a la altura exacta de los neumáticos. Ubicarlos en el piso bajo, simétricos respecto al centro de masa, minimiza drásticamente las lecturas falsas causadas por el cabeceo (frenada) o el balanceo (giro) del chasis. Esto asegura que el algoritmo de estabilización reciba datos limpios y constantes de la distancia real hacia las paredes de la pista para mantener una trayectoria perfectamente recta.

<div align="center">

<img width="1600" height="1200" alt="WhatsApp Image 2026-06-18 at 11 34 59 PM" src="https://github.com/user-attachments/assets/5bea7abe-f434-4bbd-9ce3-3c26d1443c42" />

</div>

- ### Batería:

	La Zeee 3S LiPo 11.1V 2200mAh 50C es una batería de polímero de litio de alto rendimiento, diseñada específicamente para entusiastas del radiocontrol (RC) que buscan un equilibrio óptimo entre peso, tamaño y potencia. Con una configuración de 3 celdas (3S) y un voltaje nominal de 11.1V, este componente proporciona la energía constante y agresiva necesaria para impulsar una amplia variedad de modelos, desde drones de carreras y aviones a escala hasta vehículos terrestres RC. Su capacidad de 2200mAh asegura un tiempo de juego o vuelo sumamente competitivo, permitiendo exprimir al máximo el rendimiento del motor sin añadir un peso excesivo que pueda comprometer la agilidad del modelo.

	El verdadero punto fuerte de esta batería radica en su tasa de descarga de 50C, lo que significa que es capaz de entregar picos de corriente elevados de forma segura cuando el acelerador lo demanda, garantizando aceleraciones explosivas y una respuesta inmediata a los mandos. Fabricada con materiales de alta calidad y una baja resistencia interna, la Zeee 3S destaca por su ciclo de vida prolongado y su estabilidad térmica durante un uso intensivo. Viene equipada habitualmente con conectores de alta conductividad (como el Deans T o XT60) y un conector de equilibrado JST-XH, lo que facilita tanto una carga segura celda por celda como una compatibilidad directa con la mayoría de los cargadores inteligentes del mercado.

<div align="center">

<img width="698" height="718" alt="Captura de pantalla 2026-06-21 185733" src="https://github.com/user-attachments/assets/165be46b-0187-4bd8-9dd5-e95a580baaea" />

</div>

- ### Presupuesto de Energía:

	Para garantizar la estabilidad operativa de nuestro carro, hemos implementado una arquitectura de alimentación redundante mediante el uso de dos baterías independientes. Esta división es fundamental para proteger la integridad de nuestros sistemas:

	- **Circuito de Potencia:** Una batería dedicada exclusivamente a la placa MegaPi, la cual gestiona los actuadores de alta demanda (el motor de tracción RS380 y el servomotor de dirección MG996R), además de los tres sensores ultrasónicos y el botón de inicio. Este aislamiento evita que las caídas de tensión (transitorios) provocadas por los arranques repentinos o el bloqueo de los motores afecten el procesado de datos.

	- **Circuito de Lógica y Visión:** Una segunda batería independiente alimenta exclusivamente a la Raspberry Pi 4 y la cámara Arducam. Esta separación es crítica; al no compartir el bus de energía con los motores, eliminamos el riesgo de interferencia electromagnética (EMI) y picos de voltaje que podrían inducir ruido en la señal de video o, en el peor de los casos, provocar reinicios inesperados del sistema de visión artificial durante la competencia.

	Esta configuración nos permite operar con la máxima seguridad, garantizando que, incluso bajo condiciones de estrés mecánico severo en la dirección y tracción, nuestro "cerebro" (Raspberry Pi) mantenga una alimentación constante y limpia para procesar la trayectoria con total precisión.

<div align="center">

| Componentes | Cantidad | Voltaje de Operación | Consumo Nominal/Pico | Consumo Total |
|---|---|---|---|---|
| **Raspberry Pi 4 B** | 1 | 5.0 V | 600 mA / 1250 mA | 1250 mA |
| **Arducam 8MP IMX219 (175°)** | 1 | 3.3 V | 250 mA | 250 mA |
| **Makeblock MegaPi (Lógica)** | 1 | 5.0 V | 100 mA | 100 mA |
| **Sensores Ultrasonido HC-SR04** | 3 | 5.0 V | 15 mA c/u | 45 mA |
| **Módulo Semáforo LED (Traffic Light)** | 1 | 5.0 V | 30 mA | 30 mA |
| **Servomotor de Dirección MG996R** | 1 | 5.0 V | 500 mA / 2500 mA | 2500 mA |
| **Motor de Tracción RS380** | 1 | 11.0 V | 2000 mA | 2000 mA |
| Total | | | 4.145 mA (4.14 A) mA | 6.175 mA (6.17 A) |

</div>

- ### Diagrama de Cableado:

	La arquitectura eléctrica de nuestro carro ha sido diseñada bajo un principio de aislamiento de buses para garantizar la fiabilidad del sistema en un entorno de alta vibración y demanda de corriente. Como se observa en nuestro diagrama de conexiones, el cableado se divide en dos dominios claramente diferenciados:

	- **Dominio de Potencia (Bus de Fuerza)**
Alimentado por la batería dedicada a actuadores, este bus de alta corriente alimenta directamente la MegaPi para los motores y el servomotor:

		- **MegaPi:** Actúa como el centro de distribución de energía principal. Recibe el voltaje directo de la batería de fuerza (7.2V - 12V) para alimentar el motor de tracción RS380 y el servomotor de dirección MG996R en sus puertos dedicados.

		- **Sistema de Tracción y Dirección:** El motor RS380 y el servo MG996R están conectados directamente a los puertos de alta potencia de la MegaPi. Hemos utilizado cables de calibre superior para minimizar la caída de tensión (voltaje drop) durante las maniobras de stall (esfuerzo máximo).

		- **Regulación y Estabilización de Voltaje (Buck Converter):** Se ha integrado un Buck Converter de 3A y 15W con salida Type-C. Este módulo step-down se encarga de reducir de forma eficiente el voltaje de la batería y estabilizarlo a unos 5.0V constantes. Su función es actuar como una barrera de protección frente a los picos de consumo y el ruido eléctrico residual generados por los motores, asegurando un suministro de energía limpio y seguro para los componentes lógicos sensibles y los sensores ultrasónicos, evitando lecturas erráticas.

	- **Dominio de Lógica (Bus de Control)**
Alimentado por la batería dedicada a la Raspberry Pi, este bus es eléctricamente independiente:

	  	- **Procesamiento de Datos:** La Raspberry Pi 4 B alimenta la cámara Arducam a través del puerto CSI, asegurando un flujo de datos de baja latencia y alta integridad.

		- **Comunicaciones (Bus I2C/UART):** La comunicación entre la Raspberry Pi y la MegaPi se realiza mediante un puente serial (USB/UART) debidamente blindado. Para evitar "ground loops" (bucles de tierra) que son la principal causa de fallos en robots autónomos, hemos unificado las tierras (GND) solo en el punto de entrada de la MegaPi, manteniendo el resto del cableado de sensores con rutas cortas y directas para minimizar la captación de EMI (Interferencia Electromagnética).

<div align="center">

<img width="2960" height="1625" alt="L-N-M@1 25x" src="https://github.com/user-attachments/assets/13e15df3-6f13-4d22-9dfd-a9a075e6561c" />

</div>

# 3.  Software 

- ### Herramientas de apoyo:

	- **Color Detector:** El entorno de iluminación en las competencias de robótica rara vez es idéntico al de nuestro laboratorio. Para evitar que el sistema de visión artificial falle por cambios en la luz ambiental (sombras, reflejos o luces LED del recinto), hemos diseñado una aplicación gráfica interactiva llamada Color-Detector.py.

	Esta herramienta nos permite calibrar en tiempo real los umbrales matemáticos de los colores de la pista (bloques rojos/verdes, líneas azules/naranjas y paredes negras) y exportar estos parámetros directamente al cerebro del robot.

	1. **Arquitectura de Procesamiento de Imagen (Pipeline)**
	A diferencia de los enfoques básicos que usan el espacio de color RGB o HSV, nuestro script transforma el flujo de video al espacio de color LAB (CIE Lab)*. Esta decisión técnica es crucial porque el espacio LAB aísla completamente la luminosidad (Canal L) de la información pura del color (Canales A y B). El proceso interno antes de mostrar la imagen sigue estos pasos:

		- **Extracción y Ecualización (CLAHE):** Tras convertir la imagen a LAB, separamos el canal de luminosidad (L) y le aplicamos un algoritmo CLAHE (Contrast Limited Adaptive Histogram Equalization). Esto redistribuye el contraste localmente, mitigando las sombras duras o los destellos en la pista sin alterar el color real de los objetos.

		- **Filtro de Suavizado (Gaussian Blur):** Se aplica un desenfoque gaussiano de 7x7 para difuminar el ruido de alta frecuencia del sensor de la cámara, evitando píxeles "muertos" o artefactos.

		- **Coperaciones Morfológicas:** Una vez que el usuario define los límites del color con los deslizadores, el script genera una máscara binaria (cv.inRange). Para limpiarla, aplicamos "Erosión" (elimina pequeños píxeles ruidosos o falsos positivos) seguida de "Dilatación" (restaura el tamaño original del objeto detectado).

	2. **Interfaz de Usuario y Flujo de Trabajo (GUI)**
	La interfaz gráfica ha sido construida con CustomTkinter para ofrecer un entorno oscuro de bajo contraste que no fatigue la vista durante las largas sesiones de calibración en los pits. El flujo de uso es el siguiente:

		- **Selección de Presets:** El operador inicia seleccionando un color base en el menú desplegable (ej. RED, GREEN, BLACK). Esto carga valores predeterminados seguros (COLOR_PRESETS).

		- **Ajuste Fino mediante Deslizadores (Sliders):** L-min / L-max: Se ajusta la tolerancia a las sombras y a los brillos.

			- **A-min / A-max: Se ajusta el espectro del eje Verde-Rojo.**

			- **B-min / B-max: Se ajusta el espectro del eje Azul-Amarillo.**
  
		*(Nota: Se utiliza la escala adaptada de OpenCV de 0 a 255 para todos los canales).*

		- **Telemetría Visual Combinada:** La pantalla principal consolida tres vistas en tiempo real (960x240 píxeles):

			- **Izquierda:** El video original crudo.

			- **Centro:** La máscara binaria (blanco sobre negro) que muestra exactamente lo que la computadora "ve" como un área válida.

			- **Derecha:** El resultado aislado (el color original extraído sobre un fondo negro) para verificar que no se estén capturando elementos del exterior de la pista.

	3. **Generación y Exportación de Archivos de Configuración**
	Para evitar modificar el código fuente principal (hardcoding) cada vez que calibramos un color, el botón "SAVE JSON" empaqueta los umbrales mínimos y máximos actuales y los exporta como un archivo .json ligero (ej. mask_red.json). Este archivo incluye un sello de tiempo (timestamp) para control de versiones y es leído dinámicamente por el robot durante el arranque en la competencia.

   	<div align="center">

	<img width="803" height="447" alt="Gemini_Generated_Image_oe7w1uoe7w1uoe7w" src="https://github.com/user-attachments/assets/8ed55c9c-b1f7-45c8-a92f-bee337e51ff2" />

	</div>

	- **ROI Detector:** Para garantizar que nuestro sistema de visión artificial procese las imágenes de forma eficiente, hemos desarrollado un script auxiliar llamado ROI-Detector.py. Esta herramienta de interfaz gráfica permite calibrar de forma interactiva las Regiones de Interés (ROIs) de la cámara, delimitando las áreas exactas donde el algoritmo debe buscar y calibrar los colores de los obstáculos (rojo/verde) y las paredes de la pista.

	El funcionamiento del script está diseñado para ser rápido e intuitivo, permitiendo al equipo reajustar los parámetros visuales en los pits antes de cada ronda si las condiciones de la pista cambian:

	1. **Inicialización de Video:** Al ejecutar el script, se abre una ventana redimensionable que captura el flujo de video en tiempo real. El código ajusta automáticamente la escala de la imagen para mantener la relación de aspecto sin distorsionar la perspectiva de la pista.

	2. **Trazado Interactivo (Mouse Callbacks):** Utilizando el cursor, el usuario puede dibujar rectángulos directamente sobre el video en vivo.

		- **Al hacer clic y arrastrar, se visualiza un cuadro amarillo (temp_rect) que muestra una vista previa del área seleccionada.**

		- **Al soltar el clic, la región queda fijada en pantalla con un recuadro verde, mostrando una etiqueta con sus dimensiones exactas en píxeles (ancho x alto).**

	3. **Gestión de Errores:** Si se comete un error al trazar las zonas, el usuario puede presionar la tecla 'C' (Clear) en su teclado para borrar instantáneamente todas las regiones dibujadas en la memoria y comenzar de nuevo.

	4. **Exportación Automática de Datos:** Una vez definidas las áreas correspondientes para escanear las líneas de giro y los bloques de color, se presiona la tecla 'ESC'. Esto cierra el flujo de video y despliega una ventana de diálogo del sistema (vía Tkinter).

	5. **Generación de Código:** El script toma las coordenadas espaciales (x1, y1, x2, y2) de cada ROI dibujada y escribe automáticamente un archivo de Python (.py). Este archivo generado contiene las estructuras de datos (usando @dataclass) listas para ser importadas directamente por el cerebro principal del robot, sin necesidad de transcribir números a mano.

	**Justificación de Ingeniería**
	La creación de esta herramienta resuelve dos problemas críticos en el desarrollo de vehículos autónomos:

	- **Optimización de Procesamiento:** Al calibrar ROIs precisas, obligamos a la Raspberry Pi a buscar colores solo en porciones muy pequeñas de la imagen en lugar de analizar el fotograma completo. Esto reduce drásticamente la carga de la CPU y mantiene el bucle de control a una alta frecuencia.

	- **Reducción de Falsos Positivos:** Al aislar el campo de visión estrictamente a la pista mediante esta calibración, evitamos que el robot detecte accidentalmente objetos externos (como los zapatos de un juez o luces de la sala) que compartan el mismo color que los obstáculos.

   	<div align="center">

	<img width="765" height="565" alt="Gemini_Generated_Image_fop2o1fop2o1fop2" src="https://github.com/user-attachments/assets/f9cc3741-7394-4642-af6d-1e69d5f4c231" />

	</div>

- ### MegaPiController:

	Esta es una descripción completa de todos los atributos y métodos de la clase, junto con sus argumentos. Te recomendamos que la consultes primero antes de pasar a las demás secciones y que, cuando clones el repositorio, la utilices como guía para orientarte en nuestro código.

  	Aquí tienes toda la documentación técnica completamente traducida al español, manteniendo exactamente el mismo formato y orden riguroso de las imágenes de referencia:

---

 **mega_pi_controller.py (clase MegaPiController)**

 **Dependencias**

* `serial`
* `time`
* `threading`
* `pandas`
* `random`
* `json`
* `cv2`
* `src.vision_controller.VisionController`
* `dataclasses.dataclass`

**Descripción del método constructor**

```python
def __init__(self, port='COM9', baudrate=115200):
    """
    Inicializa la conexión serial con la placa MegaPi y registra los subsistemas.
    Si la conexión falla, termina el proceso con un mensaje de error crítico.
    """

```

El constructor establece un canal de comunicación a través de puerto serial por hardware con el microcontrolador MegaPi. Inicia automáticamente un hilo de escucha en segundo plano (`_read_telemetry`) para capturar las métricas de hardware entrantes de forma asíncrona, inicializa el subsistema de visión artificial (`VisionController`), carga las máscaras de color predefinidas desde estructuras JSON específicas y prepara los registros internos, las variables de estado y las Regiones de Interés (ROIs) para el seguimiento espacial y de líneas.

<div align="center">

**Descripción de atributos:**

| Atributo | Tipo de dato | Funcionalidad |
| --- | --- | --- |
| `ser` | `serial.Serial` | Representa el canal de comunicación serial por hardware de bajo nivel con la MegaPi. |
| `dist_front` | `int` | Almacena el valor de distancia en tiempo real (cm) capturado por el sensor ultrasónico central. |
| `dist_left` | `int` | Almacena el valor de distancia en tiempo real (cm) capturado por el sensor ultrasónico izquierdo. |
| `dist_right` | `int` | Almacena el valor de distancia en tiempo real (cm) capturado por el sensor ultrasónico derecho. |
| `ir_left` | `int` | Almacena el valor porcentual bruto de reflectancia ($0\%$ a $100\%$) del sensor IR izquierdo TCRT5000. |
| `ir_right` | `int` | Almacena el valor porcentual bruto de reflectancia ($0\%$ a $100\%$) del sensor IR derecho TCRT5000. |
| `data_log` | `list[dict]` | Registro volátil en memoria utilizado para encolar los pasos de telemetría destinados al guardado de datos de entrenamiento. |
| `log_index` | `int` | Contador de pasos continuo auto-incrementable para el dataframe del registro de telemetría. |
| `vision` | `VisionController` | Módulo central instanciado responsable de las capturas de fotogramas y del mapeo de contornos LAB/HSV. |
| `running` | `bool` | Variable booleana de control de ejecución de alto nivel utilizada para terminar de forma segura las operaciones del hilo en segundo plano. |
| `reader_thread` | `threading.Thread` | Hilo de trabajo daemon asíncrono dedicado a sondear los paquetes de carga útil serial entrantes. |
| `button_value` | `int` | Representación binaria del estado del botón físico integrado en la placa para el inicio del sistema. |
| `turning_direction` | `int` | Rastrea la configuración del diseño del carril ($0$: No asignado, $1$: Sentido horario/Azul, $2$: Sentido antihorario/Naranja). |
| `rois` | `list[ROI]` | Define cuadros de procesamiento fijos en código para el análisis del área de la pared frontal y las líneas de la pista. |

</div

**Descripción de métodos:**

<div align="center">

| Método | Argumentos | Retorno | Descripción |
| --- | --- | --- | --- |
| `_read_telemetry()` | Ninguno | `None` | Hilo de trabajo de sondeo continuo. Decodifica un formato de carga útil rígido de 8 bytes prefijado por un byte de cabecera `0xAA`. |
| `_send_command()` | `action: int`, `v1: int`, `v2: int` | `None` | Empaqueta y transmite instrucciones de protocolo de control de bajo nivel de 5 bytes prefijadas con una bandera de comando `0xFF`. |
| `get_masks()` | `color: str` | `list` | Abre los archivos de configuración local de matrices de color y extrae los arreglos de límites numéricos. |
| `load_masks()` | Ninguno | `None` | Método de arranque secuencial que mapea los límites de los colores rojo, verde, azul, naranja y negro dentro del objeto. |
| `obtenerarea_frontal()` | Ninguno | `None` | Consulta los volúmenes de masa de contornos negros a lo largo de la ROI del horizonte frontal superior. |
| `obtener_linea_azul()` | Ninguno | `None` | Segmenta y evalúa el perfil del diseño de la línea de seguimiento buscando activadores de la pista azul. |
| `obtener_linea_naranja()` | Ninguno | `None` | Segmenta y evalúa el perfil del diseño de la línea de seguimiento buscando activadores de la pista naranja. |
| `debug_UI()` | Ninguno | `None` | Motor de superposición gráfica que muestra los bucles de seguimiento dinámico de visión artificial en una ventana de fotograma local. |
| `log_step()` | `action_code: int` | `None` | Añade los valores de las variables en tiempo real (ultrasónicos, infrarrojos) al arreglo del registro local. |
| `move_forward()` | `speed: int`, `log: bool` | `None` | Invoca los actuadores de tracción de bajo nivel para fijar la marcha hacia adelante a las velocidades seleccionadas. |
| `move_backward()` | `angle: int`, `speed: int`, `log: bool` | `None` | Activa vectores de movimiento en reversa mientras fija los eslabones de dirección a un ángulo de escape. |
| `turn_direction()` | Ninguno | `None` | Macro de control reactivo que enruta los pasos de giro basándose en los estados actuales de dirección. |
| `turn_left()` | `angle: int`, `speed: int`, `log: bool` | `None` | Ajusta los eslabones del servo mecánico Ackermann a ángulos cerrados hacia la izquierda bajo velocidades de tracción fijas. |
| `turn_right()` | `angle: int`, `speed: int`, `log: bool` | `None` | Ajusta los eslabones del servo mecánico Ackermann a ángulos cerrados hacia la derecha bajo velocidades de tracción fijas. |
| `turn_center()` | `log: bool` | `None` | Recalibra los pulsos del servo de dirección activa de vuelta a las coordenadas del centro geométrico. |
| `stop()` | `log: bool` | `None` | Desactiva los registros de velocidad activos de inmediato para cortar la energía de los motores y detener el vehículo. |
| `get_distances()` | Ninguno | `tuple[int, int, int]` | Getter estándar de telemetría que devuelve una tupla compuesta por las métricas actuales de los sensores (frontal, izquierdo, derecho). |
| `get_ir_reflectance()` | Ninguno | `tuple[int, int]` | Devuelve una tupla en tiempo real que contiene los porcentajes de reflectividad infrarroja localizada ($0-100\%$). |
| `save_data_to_csv()` | `filename: str` | `None` | Compila los volcados de datos encolados directamente en estructuras mapeadas por índices en el disco a través de Pandas. |
| `close()` | Ninguno | `None` | Libera los manejadores de procesos, envía un comando de parada total y cierra de forma segura los puertos seriales abiertos. |
| `start()` | Ninguno | `bool` | Evalúa los estados del botón. Devuelve `True` si el botón está liberado (HIGH/0), manteniendo el bucle en ejecución. |

</div>

- ### Arduino Controller:

	- Open Challenge:
  
		- **Open Challenge Video:**

		<div align="center">
			
		Open Challenge Video (https://youtu.be/WPSj0BXfQ5U)

		*Demostración de la navegación autónoma y el control de la velocidad en una pista dinámica.*

		</div>

		- **Estrategia:** La estrategia diseñada para abordar el Open Challenge se fundamenta en un sistema de navegación rápido y de alta predictibilidad. El objetivo es maximizar la velocidad constante (VELOCIDAD_BASE = 130) manteniendo el chasis estable mediante un enfoque de "Sensor Fusión" (cámara + ultrasonidos). 

			El comportamiento dinámico del vehículo se rige por una máquina de estados finitos que conmuta entre la navegación lineal, giros cerrados y el cierre de carrera.

			- **Estado de Ejecución de Esquinas (Giros de 90°)**
			A velocidades altas, un lazo de control PID estándar no tiene la capacidad de respuesta física para tomar curvas ortogonales sin derrapar o chocar. Por ello, se diseñó un 	estado de interrupción. Cuando la cámara detecta una saturación de pista (área negra mayor a 6500 px) y el sistema ya conoce el sentido del circuito (`LNM.turning_direction != 0`), el robot asume una esquina de 90°. 

			En este instante crítico, el software suspende inmediatamente el control PID visual, limpia las variables de error e integral a cero para evitar acumulación (windup), y ejecuta la subrutina `LNM.turn_direction()`, bloqueando la dirección en su ángulo máximo mecanico. El vehículo sostiene este giro a ciegas hasta que los sensores confirman la salida: el área negra debe descender de los 6500 px y el sensor ultrasónico frontal debe medir un espacio libre superior a 80 cm. Al cumplirse simultáneamente, se reanuda el centrado PID lateral.

			- **Registro de Vueltas y Temporización Asíncrona**
La telemetría para el conteo de vueltas se realiza mediante la discriminación de las marcas cromáticas transversales en la zona de meta, a las cuales denominamos **loops** (naranja o azul).

			Al arrancar, el sentido de giro es desconocido. En el primer paso por la meta, si se registra un contorno cromático con un área masiva (mayor a 1200 px), el robot fija de manera permanente su sentido de carrera en memoria. A partir de ahí, se activa el control de conteo no bloqueante. Al cruzar el loop con un área mayor a 500 px, se incrementa el contador general. 

			Para erradicar los falsos positivos generados por la alta frecuencia de lectura del microcontrolador al pasar sobre una misma marca, se implementó un temporizador de guarda de 1.1 segundos. La lógica interna fluye de la siguiente manera:

			<div align="center">

			untitled@1 25x (5)

			</div>
  
			- **Mecanismo de Parada Segura**
			El reglamento exige que el robot finalice su recorrido tras la vuelta número 12. Interrumpir la energía de los motores de forma abrupta directamente sobre la línea de meta provocaría un derrape severo o la salida de pista debido a la alta inercia que arrastra el chasis a una velocidad de 130.

			Para mitigar este estrés mecánico, el software inicia un procedimiento de parada controlada. Al registrar el loop número 12, se levanta la bandera end_game_triggered y se captura el tiempo de reloj en end_game_timer. El vehículo continúa ejecutando activamente sus lazos PID de centrado, evitación de paredes y tracción durante exactamente 1 segundo extra de gracia. Una vez que este margen matemático expira, el sistema rompe el bucle principal y llama a la función LNM.stop(), garantizando que el robot disipe su inercia de forma suave y se detenga legalmente dentro de los márgenes del circuito.

		- **Diagrama de Flujo:**

	<div align="center">

	untitled@1 25x (3)

	</div>

	- **Obstacle Challenge:**

	- **Estrategia:** La estrategia diseñada para abordar el segundo reto (evasión de obstáculos) se construye de forma modular sobre la base arquitectónica de la ronda abierta. Se conservan las Regiones de Interés laterales (`roi_izq` y `roi_der`), la resolución de la cámara y los filtros de segmentación de color base.

		El núcleo de este reto radica en la interpretación semántica del entorno según las reglas oficiales de la competencia: los pilares actúan como señales direccionales que indican el carril de paso correcto. Para cumplir con esta lógica de navegación de manera robusta a una velocidad constante (`VELOCIDAD_BASE = 68`), el software se estructuró sobre tres pilares fundamentales:

		- **Base del Reto Abierto (Navegación Línea Base):** Conserva el control de centrado mediante la diferencia de áreas de líneas y el fallback de seguridad asistido por ultrasonidos.
   
		- **Técnica de Selección de Carril (Visión Computacional):** Segmentación por color a larga distancia mediante una nueva Región de Interés frontal expandida (ROI_OBSTACULOS).
    
		- **Máquina de Estados Asíncrona:** Algoritmos de control dedicados para la evasión precisa y el retorno seguro al carril.

	- **ROIS:** Para anticipar la trayectoria de los pilares sin interferir con la lectura de las líneas guía del suelo, se implementó una zona de escaneo central denominada ROI_OBSTACULOS con dimensiones optimizadas en píxeles `ROI(30, 30, 610, 320)`. Esta configuración permite procesar los objetos antes de que entren en el umbral crítico de colisión frontal.
Adicionalmente, el sistema implementa dos lazos de control PID independientes con sintonizaciones diferenciadas según las necesidades dinámicas del vehículo:

		- **PID de Línea Estándar:** Configurado con valores conservadores (`Kp = 0.015`, `Kd = 0.035`) para mantener transiciones suaves y un desplazamiento lineal estable en rectas.
  
		- **PID de Evasión de Obstáculos:** Configurado con una respuesta altamente agresiva (`Kp = 0.32`, `Kd = 0.01`). El término proporcional elevado garantiza que el vehículo responda con un torque de dirección inmediato ante el desplazamiento del pilar en la imagen, mientras que el término derivativo amortigua el retorno para evitar que la parte trasera del chasis (cola) derrape y golpee el obstáculo.

		- **Implementación de la Máquina de Estados de Navegación:** El comportamiento dinámico de Halbi the Green se rige por una máquina de estados finitos que conmuta de forma asíncrona entre 	tres modos de operación para asegurar que las lógicas de centrado y evasión no entren en conflicto.

	- **Estado 1:** LINEAL (Navegación Base y Curvas Cerradas)
    
		Es el estado por defecto del robot. Mientras se encuentra en este modo, el vehículo ejecuta de forma prioritaria el centrado geométrico calculando el error entre las áreas negras laterales (`error = black_areas[1] - black_areas[0]`). Si el sensor de ultrasonido frontal detecta una pared a corta distancia (`front_dist < 90 cm`) en copresencia con una alta densidad de pixeles negros de pista (`LNM.black_area > 8000`), el estado se bloquea temporalmente bajo la bandera girando = True para forzar un giro de esquina cerrada de 90°. De manera simultánea, el método procesar_obstaculos() analiza los contornos máximos filtrados bajo las máscaras mask_red y mask_green. La transición hacia el estado de evasión se activa inmediatamente cuando el área de un contorno supera los umbrales de ruido calibrados:

		<div align="center">
		
		**Pilar Verde: Área $> 350 \text{ px} \rightarrow$ Transición a ESQUIVANDO | memoria_lado = "IZQUIERDA" (El pilar se debe dejar a la izquierda).**
   
		**Pilar Rojo: Área $> 300 \text{ px} \rightarrow$ Transición a ESQUIVANDO | memoria_lado = "DERECHA" (El pilar se debe dejar a la derecha).**

		</div>
		
	- **Estado 2:** ESQUIVANDO (Lazo de Control de Evasión)

		Al entrar en este modo, el PID de líneas se suspende y el control de dirección pasa al lazo PID de obstáculos. El algoritmo persigue un Setpoint o punto de consigna absoluto en los extremos del cuadro visual para forzar al carro a abrirse hacia el carril libre:

		<div align="center">
		
		**Para pilares verdes (dejar a la izquierda), se busca el `SETPOINT_VERDE = 549` (extremo derecho del marco).**

		**Para pilares rojos (dejar a la derecha), se busca el `SETPOINT_ROJO = 50` (extremo izquierdo del marco).**

		</div>

		- **Mecanismo de Tiempo de Gracia:** Debido a la agresividad del giro, es común que el pilar salga del campo visual de la cámara antes de que el vehículo lo haya superado físicamente.

		Para evitar que el robot regrese prematuramente al centro de la pista y colisione con el obstáculo, se implementó un temporizador de inercia (`TIEMPO_GRACIA = 0.2 segundos`). Si el área del pilar cae a cero, el sistema mantiene el cálculo del último error registrado (`error_obs = prev_error`), sosteniendo el ángulo de giro por hardware durante el tiempo de gracia antes de conmutar al estado REBASANDO.

		- **Seguridad por Encajonamiento:** Si los sensores ultrasónicos detectan que el vehículo se está aproximando peligrosamente a la pared exterior del circuito debido a la maniobra de esquiva (`left_dist o right_dist < DIST_MIN_PARED` de $18.0\text{ cm}$), la máquina aborta el lazo PID de visión y fuerza la transición inmediata al estado de rebase para proteger la integridad estructural.
  
	- **Estado 3:** REBASANDO (Zona de Seguridad y Retorno)
    
		Este estado garantiza que la parte posterior del chasis rebase completamente el pilar antes de restablecer las condiciones de carrera lineal. Dado que la cámara ya no posee contacto visual con el obstáculo, el control se delega a la telemetría de los sensores ultrasónicos laterales. El vehículo mantiene un ángulo de compensación controlado según el lado memorizado para evitar rozar la pared lateral. La máquina de estados no permite el regreso al modo LINEAL hasta que el sensor de ultrasonido del lado opuesto al pilar registre una distancia libre mayor a $40\text{ cm}$ (`left_dist > 40 o right_dist > 40`). Esta holgura asegura de forma matemática que el volumen total del robot ha despejado la posición del pilar, evitando enganches con las esquinas traseras o la base del obstáculo.

		Como última capa de protección ante pérdidas de tracking visual o escenarios de colisión inminente, el ciclo de control ejecuta en cada iteración una subrutina de freno de mano físico. Si el ultrasonido frontal registra una distancia menor a `DIST_MIN_CHOQUE` ($12.0\text{ cm}$), el vehículo interrumpe la energía de los motores mediante `LNM.stop()` y calcula un ángulo de escape inverso de manera dinámica:

		<div align="center">
	
	  	**Ángulo Escapatoria = 160°**

		</div>

		El robot realiza una maniobra de retroceso a alta potencia (`speed = 85`) durante $0.75$ segundos, resetea las variables integrales del PID a cero y reestablece el estado de carrera a LINEAL, garantizando la resiliencia del software ante condiciones críticas de atasco ambiental.

		- **Diagrama de Flujo:**

		<div align="center">

		untitled@1 25x (4)

		</div>

		<div align="center">

	- **Representación Gráfica de los Casos**

  		```
		======================================================================================
		 DISTRIBUCIÓN TOTAL DE ESCENARIOS (26 CASOS TOTALES EN JUEGO)
		======================================================================================
		
		 CASOS CON 2 OBSTÁCULOS (4 variantes de color por cada posición espacial)
		 ---------------------------------------------------------------------------
		 [Caso 1]       Muro Izquierdo: [🟥]  |  Muro Derecho: [🟥]  --> Variante 1
		                Muro Izquierdo: [🟥]  |  Muro Derecho: [🟩]  --> Variante 2
		                Muro Izquierdo: [🟩]  |  Muro Derecho: [🟥]  --> Variante 3
		                Muro Izquierdo: [🟩]  |  Muro Derecho: [🟩]  --> Variante 4
		
		 [Caso 9]       Arriba Izq:     [🟥]  |  Arriba Der:   [🟥]  --> Variante 1
		                Arriba Izq:     [🟥]  |  Arriba Der:   [🟩]  --> Variante 2
		                Arriba Izq:     [🟩]  |  Arriba Der:   [🟥]  --> Variante 3
		                Arriba Izq:     [🟩]  |  Arriba Der:   [🟩]  --> Variante 4
		
		 [Caso 10]      Abajo Izq:      [🟥]  |  Abajo Der:    [🟥]  --> Variante 1
		                Abajo Izq:      [🟥]  |  Abajo Der:    [🟩]  --> Variante 2
		                Abajo Izq:      [🟩]  |  Abajo Der:    [🟥]  --> Variante 3
		                Abajo Izq:      [🟩]  |  Abajo Der:    [🟩]  --> Variante 4

		 CASOS CON 1 OBSTÁCULO (2 variantes de color por cada posición espacial)
		 -----------------------------------------------------------------------
		 [Caso 2]       Centro:         [🟥] (Variante 1)  |  [🟩] (Variante 2)
		 [Caso 3]       Arriba Centro:  [🟥] (Variante 1)  |  [🟩] (Variante 2)
		 [Caso 4]       Abajo Centro:   [🟥] (Variante 1)  |  [🟩] (Variante 2)
		 [Caso 5]       Arriba Der:     [🟥] (Variante 1)  |  [🟩] (Variante 2)
		 [Caso 6]       Centro Der:     [🟥] (Variante 1)  |  [🟩] (Variante 2)
		 [Caso 7]       Arriba Izq:     [🟥] (Variante 1)  |  [🟩] (Variante 2)
		 [Caso 8]       Abajo Izq:      [🟥] (Variante 1)  |  [🟩] (Variante 2)
    	```

		</div>

# 4. Challenges

- ### Problemas de Hardware:

	**Objetivo:** Completar tres vueltas de forma autónoma en circuitos configurados dinámicamente.

	### Problemas de espaciamiento

	Durante el desarrollo temprano de *Halbi the Green*, se presentaron inconvenientes con respecto al posicionamiento de los componentes dentro del chasis base (sin modificar). Debido a que los componentes ocupaban más espacio del disponible, el problema se resolvió temporalmente fijándolos con cinta aislante. Aunque esto funcionó de forma provisional, no era una solución viable a largo plazo. 

	Por ello, se decidió implementar una serie de bases impresas en 3D pensadas para agregar **dos niveles adicionales** al vehículo y **tres soportes complementarios** (dos laterales y uno frontal) para ubicar los sensores de ultrasonido, los cuales originalmente no tenían un lugar asignado.

	De manera más específica, los problemas de espaciamiento y sus respectivas soluciones fueron los siguientes:

	- **Espacio ocupado por las baterías:**

		- *Problema:* Ocupaban demasiado volumen en el chasis y no dejaban espacio para ubicar los componentes de forma cómoda.

    	- *Solución:* Se les diseñó una base a medida para ubicarlas en el centro del robot y, sobre esta estructura, se construyó el piso superior.
       
	- **Anclaje de sensores de ultrasonido:**
   
		- *Problema:* No tenían puntos previstos para anclarlos al chasis original.

    	- *Solución:* Se diseñaron 3 bases impresas que van adjuntas a 3 caras del chasis.
      
    - *Nota técnica:* Esta solución no fue del todo ideal, ya que estas bases sobresalen un poco de la estructura, causando atascamientos mecánicos cuando el vehículo pasa muy cerca de una esquina.
      
	* **Ubicación de la cámara y controlador:**
 
  		- *Problema:* No había lugar físico para situar la cámara ni la placa de procesamiento.
  
   		- *Solución:* Sobre la base de las baterías se diseñó un soporte dedicado para la Raspberry Pi y la cámara. Esta última incluye una base con ángulo graduable para poder ajustar el punto de vista del lente de manera cómoda y precisa.

	* **Problemas con las conexiones (Cableado)**

		- *Problema:* Al tener cables sueltos y expuestos, estos se quedaban atascados constantemente con el entorno e incluso se llevaban por delante los obstáculos del circuito en algunas ocasiones.
  
		- *Solución:* Se reorganizaron por completo las conexiones para eliminar los bucles y partes sobresalientes del cableado.

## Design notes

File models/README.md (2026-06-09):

### 3D Printed Components & Attachments

During the development of the vehicle, structural space constraints on the stock chassis made it unfeasible to mount all electronic and mechanical components directly to the base plate. To maximize spatial efficiency and maintain a low center of gravity, we designed and 3D-printed several custom modular attachments. These components extend the chassis vertically and provide secure, vibration-resistant housings for our specialized hardware.

---

| Component & Preview | Design & Geometry | Engineering Purpose |
| :--- | :--- | :--- |
| **Battery Case**<br><br>BatteryCase | Designed as a vertical tower cage structured with four reinforced pillars on each side, integrated directly onto a solid mounting base with corner screw eyelets. The side walls feature large circular cutouts to minimize material weight while allowing maximum passive airflow to prevent thermal stress on the LiPo cells during high discharge rates. The top pillars include slotted retention eyelets for secure strap fastening. | Centralizes the combined mass of the battery cells vertically along the central geometric axis of the chassis. This open-cage design ensures quick access for battery replacement between runs while providing rigid structural containment against lateral inertia forces during high-speed cornering. |
| **Camera Case**<br><br>CameraCase | A compact, rectangular protective enclosure specifically tailored to encapsulate the IMX219 (Arducam) sensor. The bottom section integrates a robust cylindrical pivot hinge featuring external locking teeth (spur gear profile) designed to mesh perfectly with a matching mounting base for mechanical angle locking. | Shields the delicate camera PCB from external debris or direct track impacts. The interlocking geared hinge allows the camera's pitch to be adjusted and mechanically locked at a precise 15-degree downward tilt angle, preventing any unwanted lens shifting caused by high-frequency chassis vibrations during operation. |
| **MegaPi Case**<br><br>MegaPiBase (1) | A robust low-profile tray equipped with four integrated, heavy-duty vertical standoffs positioned at the corners to secure the main PCB. The base plate features internal layout guides and structural clearance cuts to avoid components on the underside of the board while keeping the profile as close to the chassis as possible. | Functions as a rigid mechanical cradle for the low-level power electronics. By elevating the PCB via the 3mm integrated standoffs, it prevents electrical short-circuits with the chassis while dampening vibrations. The completely open perimeter guarantees immediate access to the motor screw terminals, power rails, and sensor ports for field maintenance. |
| **RaspberryPi Base**<br><br>RaspberryPiBase (1) | A flat, mid-level modular platform featuring four integrated corner standoffs to mount the Raspberry Pi 4 safely. The front section of the base integrates a dual-ear hinge mount equipped with internal locking teeth that mate directly with the Camera Case hinge. | Serves as a dual-purpose structural bridge. It provides a stable, elevated mount for the high-level on-board computer, ensuring optimal heat dissipation via natural convection to prevent CPU thermal throttling. Concurrently, its integrated geared mount firmly locks the camera assembly at the front, eliminating the need for extra components and saving valuable chassis space. |
| **Ultrasonic Case**<br><br>UltrasonicSensorCase | A compact, dual-barrel protective bracket custom-tailored to snugly encapsulate the transmitter and receiver cylinders of the ultrasonic sensor module. It features integrated rear mounting tabs and lower flanges for seamless mechanical coupling to the forward crossbeams of the chassis frame. | Provides a rigid, vibration-isolated housing that keeps the ultrasonic sensor perfectly perpendicular to the track's horizontal plane. This precise alignment eliminates acoustic signal distortion and wave scattering, ensuring highly accurate real-time distance measurements for obstacle detection and emergency braking maps. |

---

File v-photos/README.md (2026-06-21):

# V-Fotos

En esta carperta se encuentra las imagenes de nuestro carro

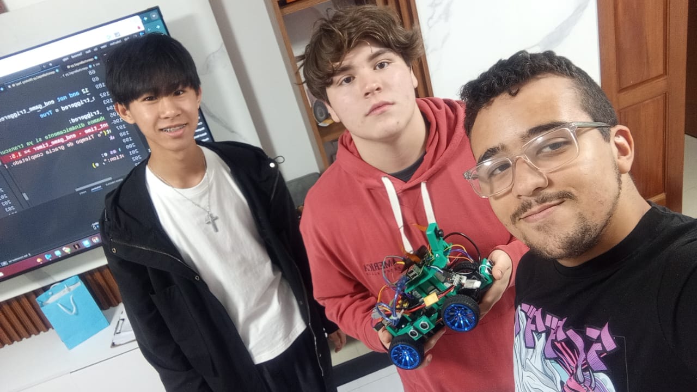
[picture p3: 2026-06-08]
t-photos/Team_pic.jpeg

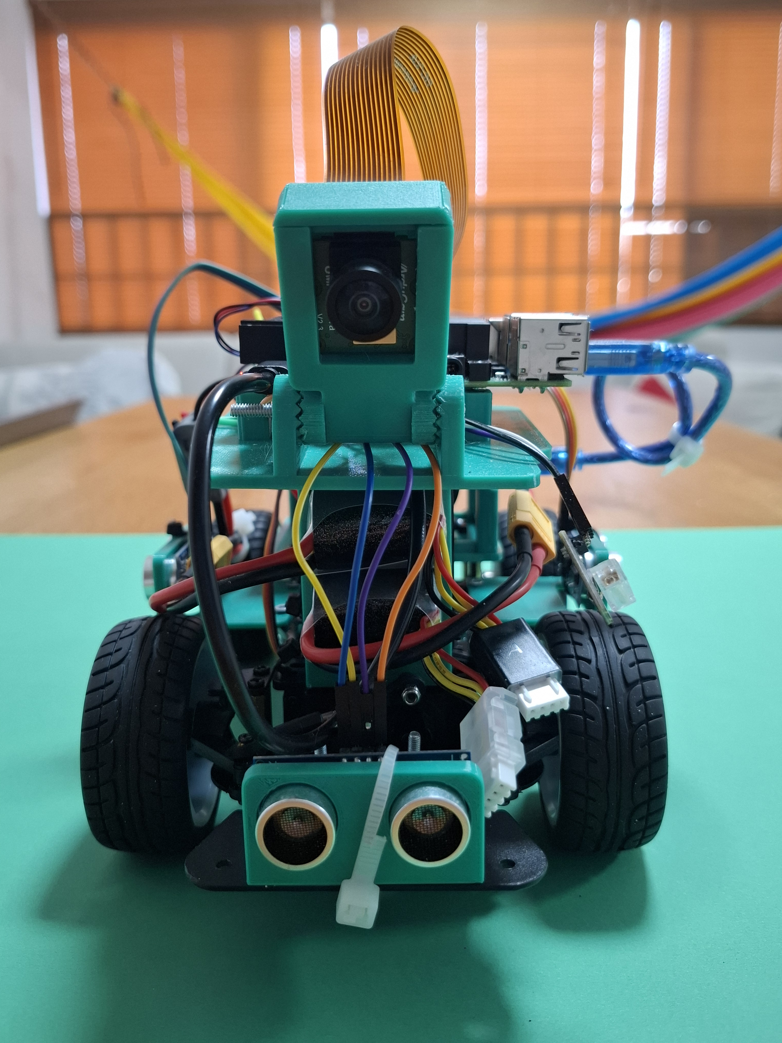
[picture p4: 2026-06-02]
v-photos/Front-Pov.jpg

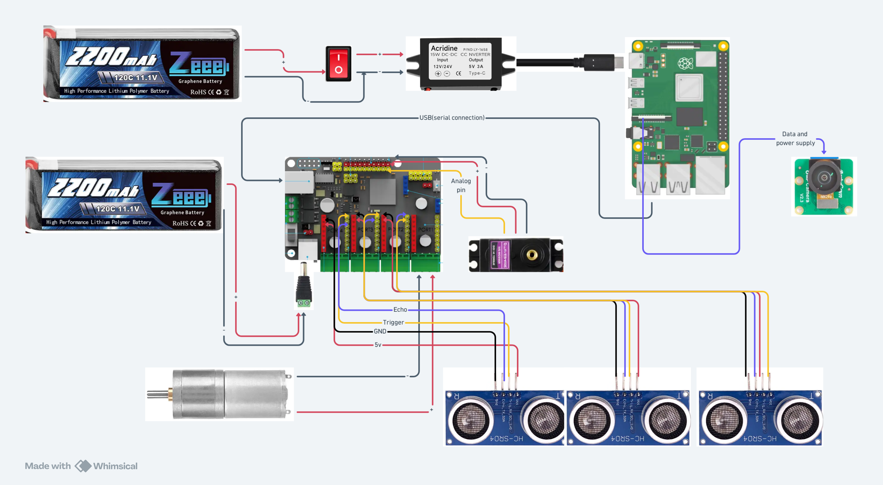
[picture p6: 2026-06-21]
schemes/diagrama-de-cableado.png

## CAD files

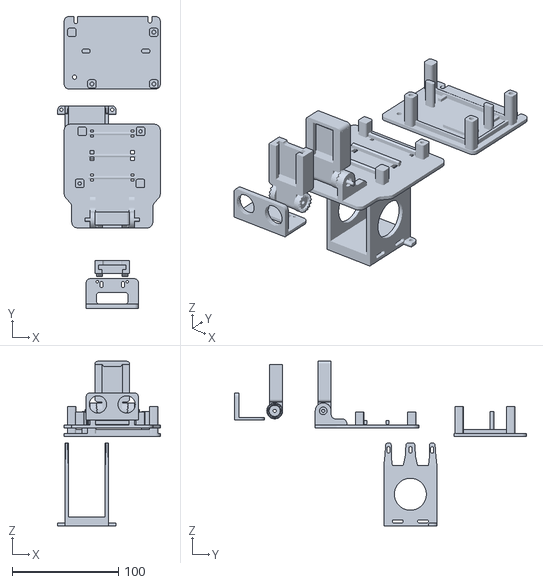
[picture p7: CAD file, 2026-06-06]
models/LNM_FI.stl
96.4 x 274.2 x 154.5

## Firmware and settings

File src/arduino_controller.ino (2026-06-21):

#include "MeMegaPi.h"
#include <Adafruit_MPU6050.h>
#include <Adafruit_Sensor.h>
#include <Wire.h>
#include "Ultrasonic.h"

// --- Constantes del Sistema ---
#define SERVO_CENTER    90
#define LEFT            0
#define RIGHT           180
#define SERIAL_BAUD     115200
#define SENSOR_TIMEOUT  25000

// Pines de Hardware
#define BUTTON           A9
#define pinServo         A7
#define trig_front       A15
#define echo_front       A14
#define trig_left        29
#define echo_left        39
#define trig_right       A11
#define echo_right       A10
#define centro           90
#define Ir_izquierda     A12  // Sensor IR Izquierdo
#define Ir_derecha       A13  // Sensor IR Derecho

Ultrasonic sensorF(A15, A14);
Ultrasonic sensorL(29, 39);
Ultrasonic sensorD(A11, A10);

class Carro {
  private:
    MeMegaPiDCMotor motorTraccion;
    Servo servoDireccion;
    Adafruit_MPU6050 mpu;
    
  public:
    // Motor conectado al Puerto 4B de la MegaPi
    Carro() : motorTraccion(PORT4B) {}

    void inicializar() {
      // Configuración del botón (Pull-up interna)
      pinMode(BUTTON, INPUT_PULLUP);

      // Configuración de pines analógicos para los TCRT5000
      pinMode(Ir_izquierda, INPUT);
      pinMode(Ir_derecha, INPUT);

      // Configuración del Servo
      servoDireccion.attach(pinServo);
      servoDireccion.write(centro);
      
      /*
      // Inicialización del MPU6050 (I2C)
      if (!mpu.begin()) {
        Serial.println("System: MPU6050 NOT Found");
      } else {
        Serial.println("System: MPU6050 Initialized");
        mpu.setAccelerometerRange(MPU6050_RANGE_8_G);
        mpu.setGyroRange(MPU6050_RANGE_500_DEG);
        mpu.setFilterBandwidth(MPU6050_BAND_21_HZ);
      }
      */
      Serial.println("System: Hardware Initialized");
    }

    // --- Lógica de Sensores ---
    bool botonPresionado() {
      return digitalRead(BUTTON) == LOW; // LOW porque usa INPUT_PULLUP
    }

    long getDistanciaFront() { return sensorF.read(); }
    long getDistanciaLeft()  { return sensorL.read(); }
    long getDistanciaRight() { return sensorD.read(); }

    // --- Métodos Nuevos: Lectura de Sensores IR (TCRT5000) ---
    // Devuelven el porcentaje de reflexión (0% a 100%)
    int getPorcentajeIRIzquierdo() {
      int valorRaw = analogRead(Ir_izquierda);
      // Mapeo de 0-1023 a 0-100%. Si necesitas invertirlo, cambia a: map(valorRaw, 0, 1023, 100, 0)
      return map(valorRaw, 0, 1023, 0, 100); 
    }

    int getPorcentajeIRDerecho() {
      int valorRaw = analogRead(Ir_derecha);
      return map(valorRaw, 0, 1023, 0, 100);
    }

    // --- Lógica de Movimiento ---
    void avanzar(byte velocidad) {
      motorTraccion.run(velocidad);
    }

    void retroceder(byte angulo, byte velocidad) {
      servoDireccion.write(centro);
      servoDireccion.write(angulo);
      motorTraccion.run(-velocidad);
    }

    void girarIzquierda(byte angulo, byte velocidad) {
      servoDireccion.write(angulo);
      motorTraccion.run(velocidad);
    }

    void girarDerecha(byte angulo, byte velocidad) {
      servoDireccion.write(angulo);
      motorTraccion.run(velocidad);
    }

    void detenerse() {
      motorTraccion.stop();
      servoDireccion.write(centro);
    }

    void girarCentro() {
      servoDireccion.write(centro);
    }
};

Carro miCarro;
unsigned long timerSensores = 0;

void setup() {
  Serial.begin(SERIAL_BAUD);
  miCarro.inicializar();
}

void loop() {
  // --- PARTE 1: Procesamiento de Comandos (Raspberry -> Arduino) ---
  if (Serial.available() >= 5) {
    byte header = Serial.read();
    if (header == 0xFF) {
      byte tipo   = Serial.read();
      byte accion = Serial.read();
      byte v1     = Serial.read(); // Velocidad o Ángulo
      byte v2     = Serial.read(); // Velocidad secundaria

      switch (accion) {
        case 1: miCarro.avanzar(v1); break;
        case 2: miCarro.retroceder(v1, v2); break;
        case 3: miCarro.girarIzquierda(v1, v2); break;
        case 4: miCarro.girarDerecha(v1, v2); break;
        case 5: miCarro.detenerse(); break;
        case 6: miCarro.girarCentro(); break;
        case 7: miCarro.inicializar(); break; // Reiniciar configuración
        default: miCarro.detenerse(); break;
      }
    }
  }

  // --- PARTE 2: Telemetría (Arduino -> Raspberry) cada 100ms ---
  if (millis() - timerSensores > 100) {
    int d_front = (int)miCarro.getDistanciaFront();
    int d_left  = (int)miCarro.getDistanciaLeft();
    int d_right = (int)miCarro.getDistanciaRight();
    byte estadoBoton = miCarro.botonPresionado() ? 1 : 0;
    
    // Obtenemos los porcentajes de los TCRT5000
    byte ir_izq = (byte)constrain(miCarro.getPorcentajeIRIzquierdo(), 0, 100);
    byte ir_der = (byte)constrain(miCarro.getPorcentajeIRDerecho(), 0, 100);
    
    // NUEVO: Paquete de Telemetría Expandido (8 bytes en total)
    Serial.write(0xAA);                        // Byte 0: Header
    Serial.write(constrain(d_front, 0, 255));  // Byte 1: Ultrasonido Frontal
    Serial.write(constrain(d_left, 0, 255));   // Byte 2: Ultrasonido Izquierda
    Serial.write(constrain(d_right, 0, 255));  // Byte 3: Ultrasonido Derecha
    Serial.write(estadoBoton);                 // Byte 4: Botón (0 o 1)
    Serial.write(ir_izq);                      // Byte 5: Porcentaje IR Izquierdo (0-100)
    Serial.write(ir_der);                      // Byte 6: Porcentaje IR Derecho (0-100)
    Serial.write(0x00);                        // Byte 7: Relleno (Padding) para mantener estructura
    
    timerSensores = millis();
  }
}

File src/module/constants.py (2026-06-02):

from dataclasses import dataclass

# Region Of Interest:

#  x1,y1-----------------
#  |                    |
#  |                    |
#  |                    |
#  -------------------x2,y2   

# --- DATA STRUCTURES ---
@dataclass
class ROI:
    x1: int; y1: int
    x2: int; y2: int

# --- HARDWARE PIN CONFIGURATION (ARDUINO) ---
IN_3 = 12
IN_4 = 11
ENB = 10 
SERVO_PIN = 9

LED_YELLOW = 7
LED_RED = 6
LED_WHITE = 5
LED_GREEN = 4
BUTTON = 3

PINS = {
    "LED": [LED_YELLOW, LED_RED, LED_WHITE, LED_GREEN],
    "BUZZER": None, 
    "SERVO": SERVO_PIN,
    "MOTOR_EN": ENB,
    "MOTOR_IN3": IN_3,
    "MOTOR_IN4": IN_4,
    "BUTTON": BUTTON
}

# --- DIRECTION TARGETS AND STEERING CONSTANTS ---
RIGHT = 0
LEFT = 180
CENTER = 84

RED_TARGET = 110 
GREEN_TARGET = 530

# --- VISION COORDINATES AND REGIONS OF INTEREST ---
CENTER_X = int(640 / 2)
CENTER_Y = int(480 / 2) + 30

OPEN_ROI_CENTER = ROI(CENTER_X - 120, CENTER_Y - 14, CENTER_X + 120, 450)
ROI_LINES = ROI(200, 370, 440, 470)

CLOSED_LEFT_ROI = ROI(0, CENTER_Y - 30, int(640 / 3), 480)
CLOSED_RIGHT_ROI = ROI(640 - int(640 / 3), CENTER_Y - 30, 640, 480)
CLOSED_CENTER_ROI = ROI(int(640 / 3), CENTER_Y - 30, 640 - int(640 / 3), 480)
CLOSED_GENERAL_ROI = ROI(0, CENTER_Y - 30, 640, 480)

# --- THRESHOLDS ---
TURN_THRESH = 30000.0
TURN_EXIT_THRESH = 10400.0

# --- LAB COLORSPACE MASKS ---
mask_red = [[0, 153, 140], [131, 198, 171]]
mask_green = [[0, 45, 0], [255, 117, 153]]

mask_blue = [[54, 124, 25], [148, 164, 121]]
mask_blue_test = [[0, 61, 17], [114, 170, 126]]

mask_orange = [[0, 163, 163], [255, 191, 204]]
mask_orange_test = [[35, 135, 86], [175, 160, 177]]

mask_black = [[0, 109, 113], [59, 137, 150]]
mask_black_test = [[0, 58, 17], [108, 169, 137]]

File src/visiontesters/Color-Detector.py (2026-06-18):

# ====================================================
# LIBRARIES
# ====================================================
import cv2 as cv
import numpy as np
import json
import datetime
import customtkinter as ctk
from tkinter import filedialog
from PIL import Image
from picamera2 import Picamera2

# ====================================================
# COMPUTER VISION SUBSYSTEM DATA STRUCTURES
# ====================================================
class ROI:
    def __init__(self, x1, y1, x2, y2):
        self.x1, self.y1 = x1, y1
        self.x2, self.y2 = x2, y2

class VisionController():
    def __init__(self):
        self.image_width  = 1080
        self.image_height = 480
        self.image_lab = None
        self.frame = None
        
        self.picam2 = Picamera2()
        config = self.picam2.create_video_configuration(
            main={"size": (self.image_width, self.image_height), "format": "RGB888"}
        )
        self.picam2.configure(config)
        self.picam2.start()

    def receive_image(self):
        self.frame = self.picam2.capture_array('main')
        self.frame = cv.flip(self.frame, 0)
        self.frame = cv.flip(self.frame, 1)

        if self.frame is None:
            print("No se pudo obtener imagen de la PiCamera.")
            return

        self.image_lab = cv.cvtColor(self.frame, cv.COLOR_BGR2LAB)
       
        l_channel, a_channel, b_channel = cv.split(self.image_lab)
       
        clahe = cv.createCLAHE(clipLimit=3.0, tileGridSize=(8, 8))
        cl_channel = clahe.apply(l_channel)
       
        self.image_lab = cv.merge((cl_channel, a_channel, b_channel))
       
        self.image_lab = cv.GaussianBlur(self.image_lab, (7, 7), 0)
        return True

    def find_mask(self, color_range, roi):
        img_segmented = self.image_lab[roi.y1:roi.y2, roi.x1:roi.x2]
        lower = np.array(color_range[0])
        upper = np.array(color_range[1])
        
        mask = cv.inRange(img_segmented, lower, upper)
        kernel = np.ones((5, 5), np.uint8)
        mask = cv.erode(mask, kernel, iterations=1)
        mask = cv.dilate(mask, kernel, iterations=1)
        return mask

# ====================================================
# COLOR CALIBRATION PRESETS
# ====================================================
COLOR_PRESETS = {
    0: {"name": "RED",      "lower": [ 30, 170, 120], "upper": [255, 255, 170]},
    1: {"name": "GREEN",    "lower": [ 30,    0, 100], "upper": [255, 100, 160]},
    2: {"name": "BLUE",     "lower": [ 30, 110,    0], "upper": [255, 150, 110]},
    3: {"name": "PURPLE",   "lower": [ 30, 160,    0], "upper": [255, 255, 110]},
    4: {"name": "ORANGE",   "lower": [ 50, 140, 150], "upper": [255, 255, 255]},
    5: {"name": "BLACK",    "lower": [  0,    0,    0], "upper": [ 60, 255, 255]}
}
COLOR_NAMES_LIST = [COLOR_PRESETS[i]["name"] for i in range(len(COLOR_PRESETS))]

# ====================================================
# GRAPHICAL USER INTERFACE APPLICATION
# ====================================================
class VisionApp(ctk.CTk):
    def __init__(self):
        super().__init__()
        
        self.title("Vision Calibration System")
        self.geometry("1300x600")
        ctk.set_appearance_mode("Dark")
        ctk.set_default_color_theme("blue")

        self.vision = VisionController()

        self.grid_columnconfigure(0, weight=1) 
        self.grid_columnconfigure(1, weight=0) 
        self.grid_rowconfigure(0, weight=1)

        # --- VIDEO PANEL ---
        self.video_frame = ctk.CTkFrame(self)
        self.video_frame.grid(row=0, column=0, padx=10, pady=10, sticky="nsew")
        self.video_label = ctk.CTkLabel(self.video_frame, text="Starting camera...")
        self.video_label.pack(expand=True, fill="both")

        # --- CONTROLS PANEL ---
        self.controls_frame = ctk.CTkFrame(self, width=350)
        self.controls_frame.grid(row=0, column=1, padx=10, pady=10, sticky="ns")

        self.color_var = ctk.StringVar(value="RED")
        self.preset_menu = ctk.CTkOptionMenu(
            self.controls_frame, 
            values=COLOR_NAMES_LIST,
            command=self.load_preset, 
            variable=self.color_var
        )
        self.preset_menu.pack(pady=20, padx=20)

        self.sliders = {}
        self.labels = {}

        def create_slider(name, default_val):
            lbl = ctk.CTkLabel(self.controls_frame, text=f"{name}: {default_val}", font=("Arial", 14, "bold"))
            lbl.pack(padx=20, pady=(5, 0), anchor="w")
            
            sl = ctk.CTkSlider(
                self.controls_frame, from_=0, to=255, 
                command=lambda v: self.update_label_text(name, v)
            )
            sl.set(default_val)
            sl.pack(padx=20, pady=(0, 10))
            
            self.labels[name] = lbl
            self.sliders[name] = sl

        create_slider("L-min", 30)
        create_slider("L-max", 255)
        create_slider("A-min", 170)
        create_slider("A-max", 255)
        create_slider("B-min", 120)
        create_slider("B-max", 170)

        self.save_btn = ctk.CTkButton(self.controls_frame, text="SAVE JSON", command=self.save_json, fg_color="#28a745", hover_color="#218838")
        self.save_btn.pack(pady=20, padx=20)

        self.status_label = ctk.CTkLabel(self.controls_frame, text="Status: READY", text_color="green")
        self.status_label.pack(pady=5)

        self.load_preset("RED")
        self.update_video_stream()

    def update_label_text(self, name, val):
        self.labels[name].configure(text=f"{name}: {int(val)}")

    def load_preset(self, color_name):
        preset = next(item for item in COLOR_PRESETS.values() if item["name"] == color_name)
        
        self.sliders["L-min"].set(preset["lower"][0])
        self.sliders["L-max"].set(preset["upper"][0])
        self.sliders["A-min"].set(preset["lower"][1])
        self.sliders["A-max"].set(preset["upper"][1])
        self.sliders["B-min"].set(preset["lower"][2])
        self.sliders["B-max"].set(preset["upper"][2])

        for name in self.sliders:
            self.update_label_text(name, self.sliders[name].get())

    def save_json(self):
        lower = [int(self.sliders["L-min"].get()), int(self.sliders["A-min"].get()), int(self.sliders["B-min"].get())]
        upper = [int(self.sliders["L-max"].get()), int(self.sliders["A-max"].get()), int(self.sliders["B-max"].get())]
        color_name = self.color_var.get()

        file_path = filedialog.asksaveasfilename(
            defaultextension=".json",
            filetypes=[("JSON files", "*.json")],
            initialfile=f"mask_{color_name.lower()}.json",
            title="Save Mask Configuration"
        )
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

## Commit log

2026-04-20 feat: Add MegaPiController for robot control and telemetry
    - Implemented MegaPiController class for handling movement, telemetry, and data logging for ML training.
    - Added methods for movement commands (forward, backward, turn left/right, stop) and logging sensor data.
    - Introduced threading for asynchronous sensor data retrieval.
    feat: Create camera test script for color detection
    - Developed camera_test.py to capture and process images for color detection using OpenCV.
    - Implemented ROI class for defining regions of interest and color segmentation logic.
    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
2026-04-24 feat: Update MegaPiController and firstchallenge for improved functionality and error handling
    [mega_pi_controller.py]
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2026-05-16 Enhance README with detailed vehicle component setup
    Expanded on the importance of component communication and the architecture of the vehicle's control system, detailing the connections and functionalities of the MegaPi, motors, servos, and ultrasonic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
2026-05-16 Enhance README with detailed vehicle architecture
    Expanded on the architectural design and component integration of the autonomous vehicle, detailing the roles of the Raspberry Pi 4 and Makeblock MegaPi, as well as the power distribution and sensor 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
2026-05-18 Refactor: Update Arduino controller constants and pin assignments; enhance MegaPi controller with vision processing and region of interest handling; add color mask JSON files for vision detection.
2026-05-19 Refactor: Update OpenCV import style and replace cv2 methods in VisionController; remove unnecessary image receiving in test script
    [vision_controller.py]
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2026-05-19 Refactor arduino_controller and testfirstchallenge: update sensor pin definitions and enhance obstacle detection logic for improved navigation
2026-05-20 Enhance navigation logic with micro-adjustments for obstacle avoidance based on distance sensors
2026-05-20 Refactor: Remove debug print statement from move_forward method and clean up testfirstchallenge script
2026-05-27 Fix: Correct video configuration format from RGB888 to BGR888 in VisionController
    [vision_controller.py]
2026-05-27 Fix: Update image format in VisionController from BGR888 to RGB888 and apply frame flipping
2026-05-27 Fix: Update image processing in VisionController to use RGB format and apply CLAHE for enhanced contrast
    [vision_controller.py]
2026-05-27 Add: Implement main control loop for MegaPi with dynamic PID steering and line detection
2026-05-27 Fix: Update image processing in VisionController and Color Detector to use RGB format and correct LAB conversion; add new color masks for blue, orange, and green
    [vision_controller.py]
2026-05-28 Refactor: Organize code structure with clear section headers for initialization, PID control, timers, and main control loop
2026-05-28 Refactor comments and improve sensor logic
    Refactor code comments and update logic for sensor and motion handling.
2026-05-28 Refactor serial communication script
    Refactor variable names and improve print statements for clarity.
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2026-05-28 Add main control loop for obstacle avoidance and PID
2026-05-30 Add motor control logic in control_motores_megapi.ino
    Initial implementation of motor control logic with command processing.
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2026-06-03 Refactor PID parameters and enhance obstacle detection
    Refactor PID controller parameters and improve obstacle detection logic.
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2026-06-03 Enhance image processing and contour detection
    Refactor image processing to support parallel frame storage and improve contour detection.
2026-06-03 Add link to steering system photo in README
    Updated README with a link to a detailed photo of the steering system.
2026-06-03 Revise power supply and battery life calculations
    Updated power supply system details and electrical calculations for clarity and consistency.
2026-06-03 Revise power and battery life calculations in README
    Updated electrical calculations for power and battery life in README.
2026-06-04 Fix color mask assignments and adjust contour processing for improved accuracy
    [mega_pi_controller.py, testfirstchallenge2.py, vision_controller.py]
2026-06-04 Fix color mask for blue and adjust contour drawing in VisionController; enhance PID controller parameters for smoother navigation
    [mega_pi_controller.py, vision_controller.py]
2026-06-04 Refactor: Remove obsolete files and consolidate obstacle avoidance logic
    - Deleted `control_motores_megapi.ino`, `firstchallenge.py`, `rois.json`, `rois.py`, `test.py`, `testfirstchallenge.py`, `testfirstchallenge2.py`, `testfreechallenge.py`, `testsecondchallenge.py` as they are no longer needed.
    - Introduced `obstacle_challenge.py` and `open_challenge.py` to streamline obstacle detection and navigation logic.
    - Updated PID control parameters for improved responsiveness and stability.
    - Enhanced corner detection and handling mechanisms for better performance in navigating challenges.
2026-06-04 Refactor: Update sensor handling and improve distance measurement logic in Carro class
2026-06-05 Refactor: Enhance obstacle detection logic and adjust PID parameters for improved navigation
2026-06-05 Fix: Add missing newline at end of arduino_controller.ino
    [LNM_FI.blend]
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2026-06-05 Fix filename formatting for Arduino controller
2026-06-05 Enhance obstacle detection and control logic with improved PID parameters and OpenCV integration
2026-06-05 Refactor obstacle detection logic and improve PID control for dynamic wall following
2026-06-05 Adjust PID parameters and refine comments for clarity in obstacle detection logic
2026-06-05 Refactor PID control for wall following by separating left and right parameters for improved navigation
2026-06-06 Adjust PID parameters for left side and refine color detection threshold for improved navigation
2026-06-06 Add debug prints for detected red and green areas in color signal processing
2026-06-06 Refactor PID controller parameters for improved responsiveness; add blue timer logic for enhanced color detection
2026-06-06 Enhance emergency braking logic with improved backward maneuvering; streamline PID controller comments for clarity
2026-06-06 Refactor PID controller comments for clarity; remove emergency brake logic and streamline main control loop
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2026-06-06 Update README with steering system details and image
    Added an image and expanded the description of the steering system and propulsion.
2026-06-06 .Blend file replaced by an .stl file
    [LNM_FI.stl]
2026-06-06 Refactor PID parameters for visual control; enhance emergency brake logic and add area-based steering adjustments
2026-06-06 Add README content for 3D printed components
    Added information about 3D printed components and their specifications.
2026-06-06 Refactor PID parameters for visual control; enhance tolerance filters and implement dynamic end game timer
    [openchallenge2.py]
2026-06-06 Update PID controllers and emergency configurations
    Refactor PID controllers and enhance emergency handling.
2026-06-06 Enhance README with component details and specifications
    Expanded the README with detailed specifications and engineering purposes for various 3D-printed components, including Battery Case, Camera Case, MegaPi Case, and RaspberryPi Base.
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2026-06-07 Fix grammatical error in propulsion description
    Corrected grammatical error in the propulsion section regarding the motor description.
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2026-06-08 Refactor emergency brake and reverse control logic
    Updated emergency brake configuration and adjusted reverse logic with PD control. Increased forward speed and modified timing for obstacle detection.
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2026-06-09 Update emergency brake to dynamic profiling strategy
    Replaced emergency brake configuration with dynamic profiling settings and adjusted related logic for movement and steering.
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2026-06-09 Adjust reverse steering angles for improved obstacle navigation
2026-06-09 Adjust PID parameters for improved obstacle avoidance and control responsiveness
2026-06-09 Refactor comments for clarity and consistency
    Removed comments on limits and clarified emergency brake section. Updated comments for obstacle avoidance logic.
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2026-06-10 Adjust obstacle detection parameters and refine reverse steering logic
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2026-06-11 Update color mask parameters and refine movement speeds for obstacle avoidance
    [mega_pi_controller.py, openchallenge2.py]
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2026-06-17 Replace Click Button with Crash Collision Sensor Module
    Updated product list and descriptions in README.md.
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2026-06-18 Correct link syntax in README for sensor module
    Fixed link formatting for Crash Collision Sensor Module.
2026-06-18 Fix link formatting for Crash Collision Sensor Module
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2026-06-18 Adjust PID parameters for line centering and obstacle avoidance; update detection thresholds for obstacles
2026-06-18 Fix power consumption value for traction motor
    Corrected the power consumption value for the traction motor in the specifications table.
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2026-06-19 Adjust grace time and PID parameters for obstacle avoidance
2026-06-19 Corrige formato y mejora la sección de problemas
    Se han corregido errores de formato y se han añadido detalles a la sección de problemas de hardware y conexiones en el README.
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2026-06-20 Enhance README with power architecture details
    Added section on power architecture and redundancy for stability.
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2026-06-20 Enhance README with PETG vs PLA comparison
    Added detailed comparison of PETG and PLA materials, including their durability, thermal stability, rigidity, chemical resistance, and dimensional accuracy.
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2026-06-20 Revise sensor arrangement and structural justification
    Updated sensor layout and justification for the autonomous vehicle design, enhancing modular architecture and stability.
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2026-06-21 Fix broken link in Arduino Controller section
    Removed a broken link to a video in the Arduino Controller section.
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2026-06-21 Fix typos and enhance clarity in README
    Corrige errores tipográficos y mejora la claridad del texto en la sección de estrategia y estados del robot.
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
